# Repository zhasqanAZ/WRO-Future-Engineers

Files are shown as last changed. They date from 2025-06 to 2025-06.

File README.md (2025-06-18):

# <h1 align="center"> ZHANYM </h1> 

This repository showcases the journey and development of our robot created for the **2025 World Robot Olympiad – Future Engineers** category.

We are **Team Zhanym WRO2025**, a duo of passionate and driven girls who designed, engineered, and built this robot from the ground up.

Here, you'll find all the documentation, design insights, and technical details behind our project.

<p align="center">
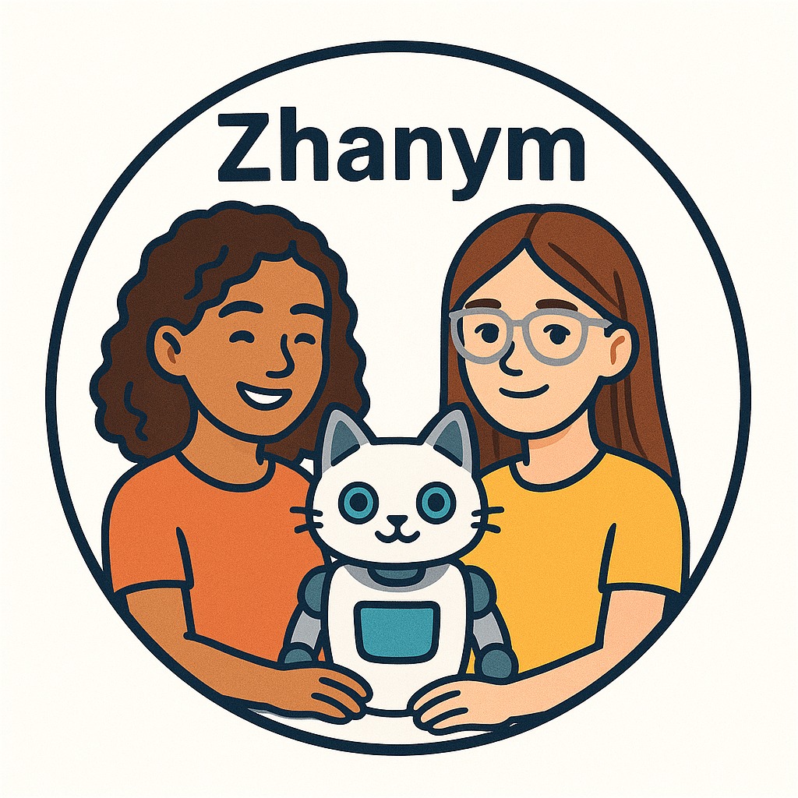
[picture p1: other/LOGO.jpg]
Team Logo
  
</p>

## Team Members 
### Khanbay Aigerim
Hello! 👋

My name is **Aigerim**, and I am **17 years old**.

This is my **second adventure** in the **WRO (World Robot Olympiad)** — a journey that fuels my passion for innovation and technology.

My first experience was back in **Grade 9**, when I took on the challenge of the **RoboMission category (Senior Division)**.  
That experience sparked my love for robotics and teamwork.

Now, I'm excited to take things to the next level as I dive into the **Future Engineers** category — where creativity, design, and real-world engineering come together! 🚀
.

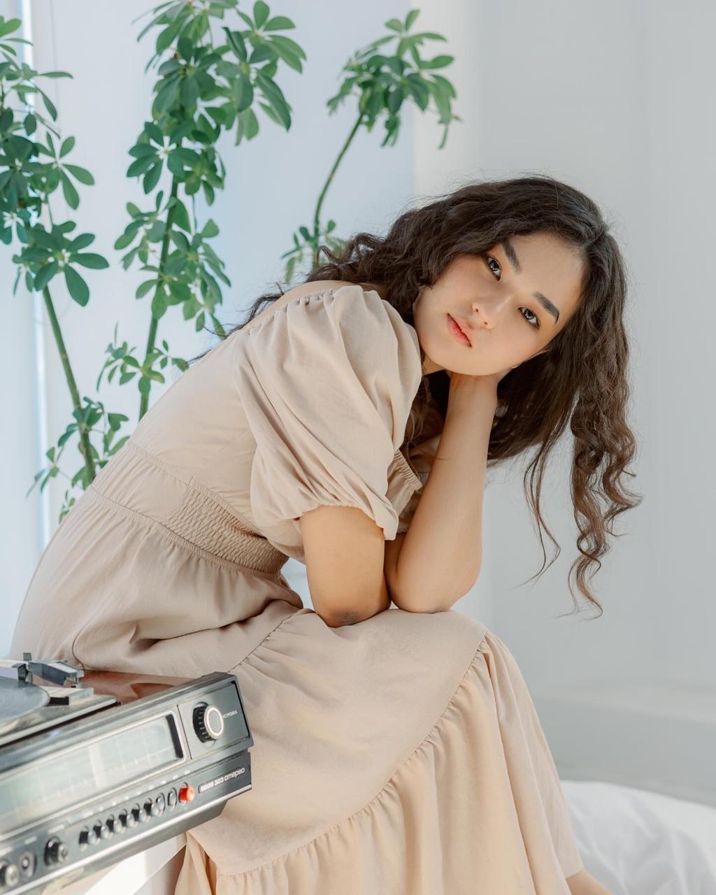
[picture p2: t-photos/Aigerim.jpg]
Aigerim


### Zharas Zhanuya
Hi! 👋

I’m **Zhanuya**, a **16-year-old student** passionate about **engineering**, **coding**, and **hands-on problem solving**.

I love working on tech projects that combine **hardware and creativity**.

Last year, I competed in the **WRO Future Engineers** category,  
and I’m excited to keep learning and building in this category! 🚀

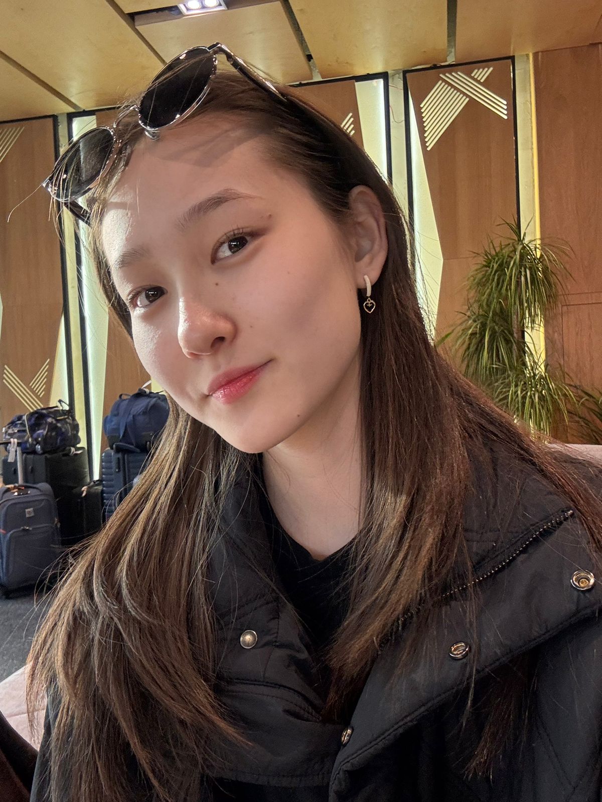
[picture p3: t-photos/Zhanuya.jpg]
Zhanuya


### 👨‍🏫 Mentor: Mister Askar
Hello! My name is **Askar**, and I am the **mentor** of this amazing team.

I’m truly happy to work with such talented and motivated students who are passionate about engineering, creativity, and robotics.

Guiding them through challenges and helping them grow is a privilege and a joy.

I also work at **Nazarbayev Intellectual School (NIS)** in **Atyrau**, where I support young minds in exploring STEM fields and developing real-world problem-solving skills.

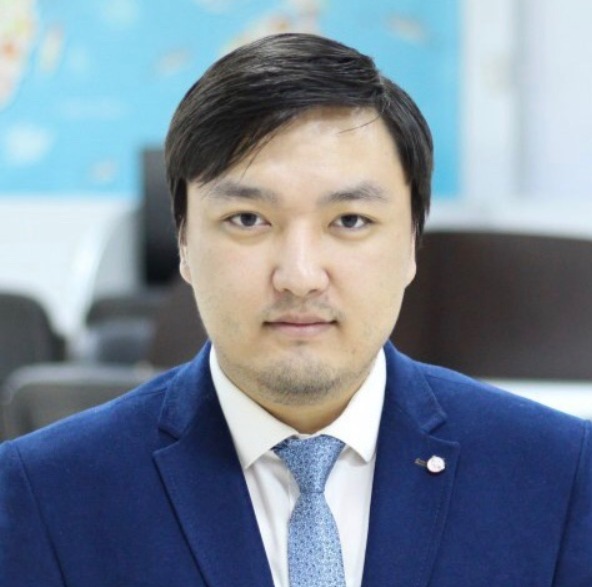
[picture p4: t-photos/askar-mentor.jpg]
Askar - Mentor


---

## Autonomous Robotic Vehicle

This autonomous robotic vehicle is capable of self-driving on a dynamically changing racetrack, completing multiple laps without human input and adapting to new configurations in each round.
<div style="width: 100%; display: flex; justify-content: center; margin-top: 40px;">
  <table style="background-color: #f0f0f0; text-align: center; border-collapse: collapse; font-family: Arial, sans-serif; transform: scale(1.2);">
    <tr>
      <td style="padding: 20px;">
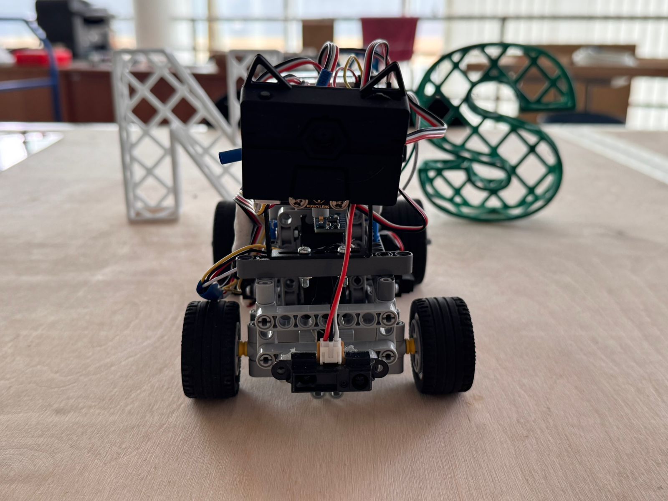
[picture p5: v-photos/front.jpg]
        <br><strong>Front</strong>
      </td>
      <td style="padding: 20px;">
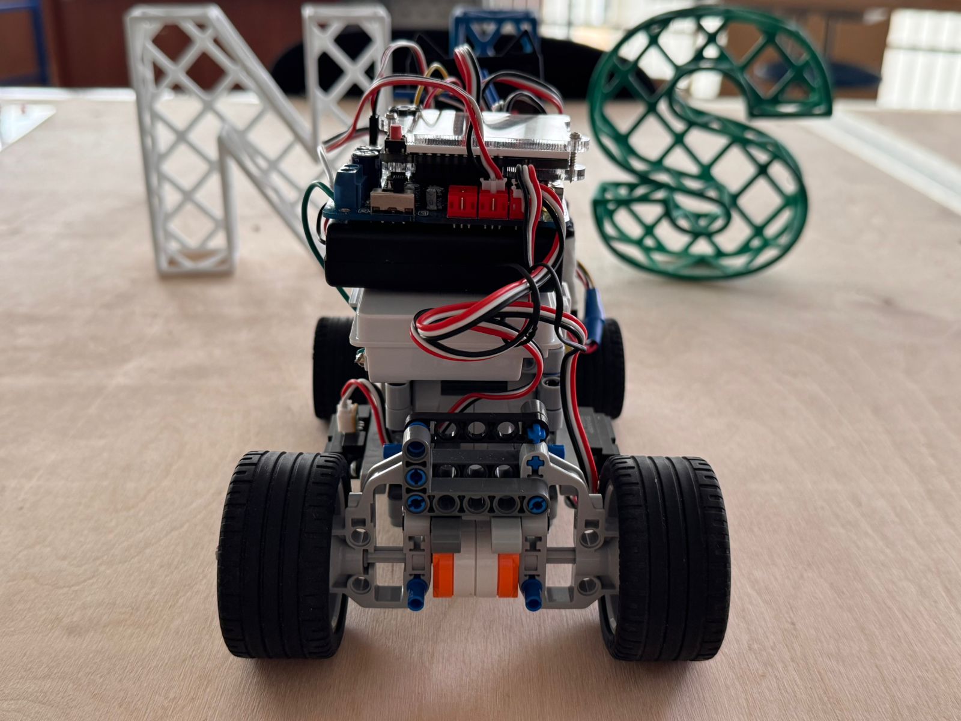
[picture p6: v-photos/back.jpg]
        <br><strong>Back</strong>
      </td>
    </tr>
    <tr>
      <td style="padding: 20px;">
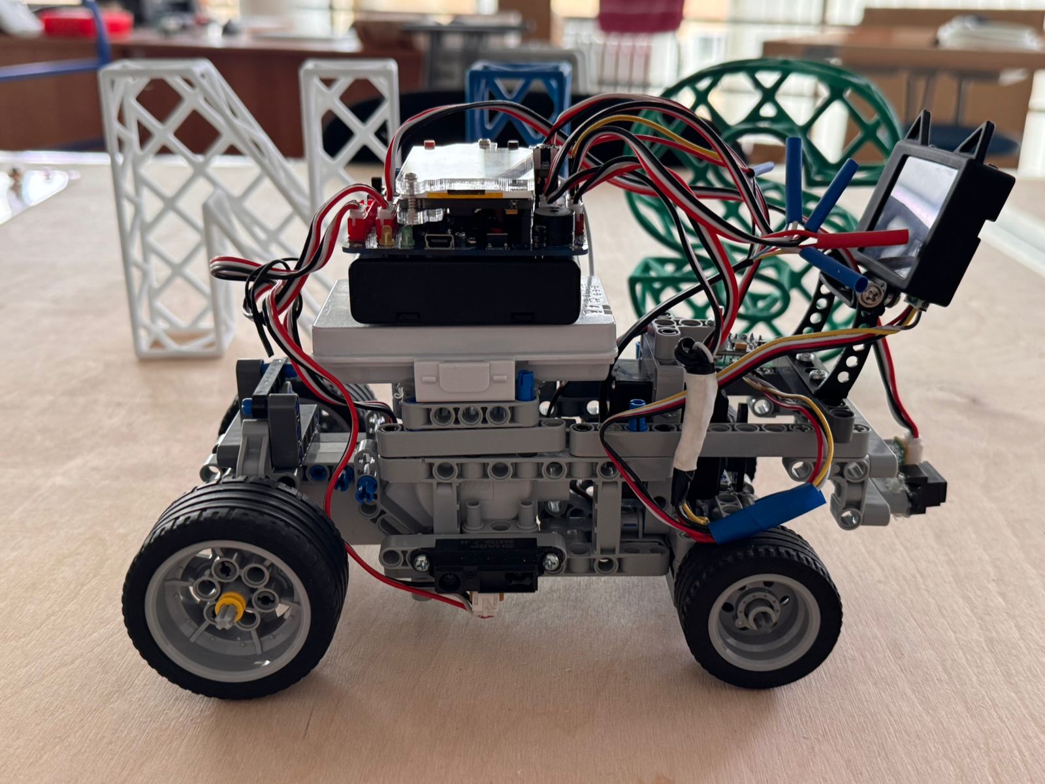
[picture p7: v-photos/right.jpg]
        <br><strong>Right</strong>
      </td>
      <td style="padding: 20px;">
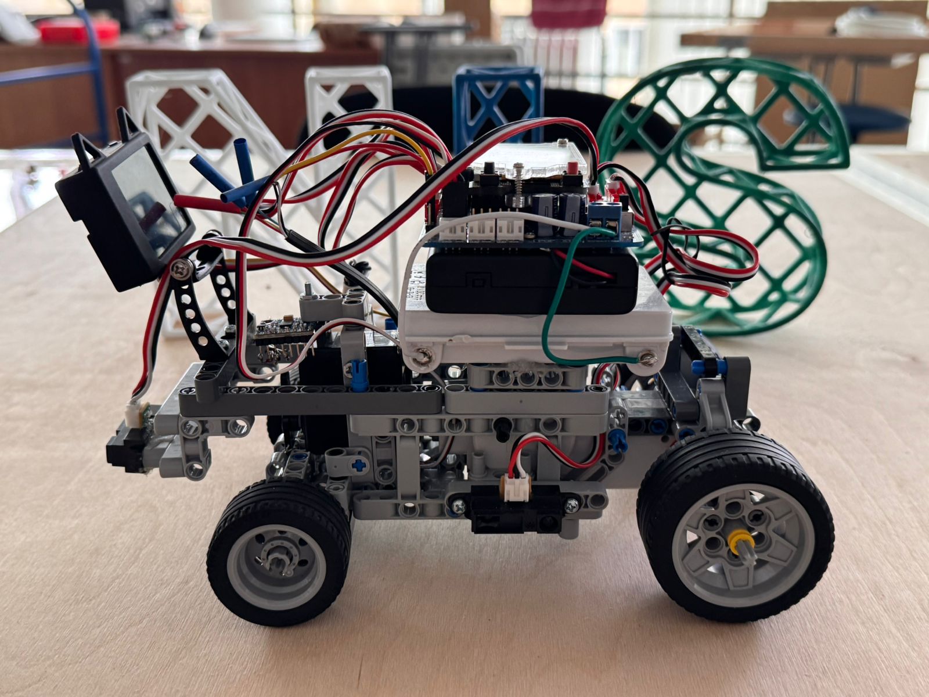
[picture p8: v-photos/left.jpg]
        <br><strong>Left</strong>
      </td>
    </tr>
    <tr>
      <td style="padding: 20px;">
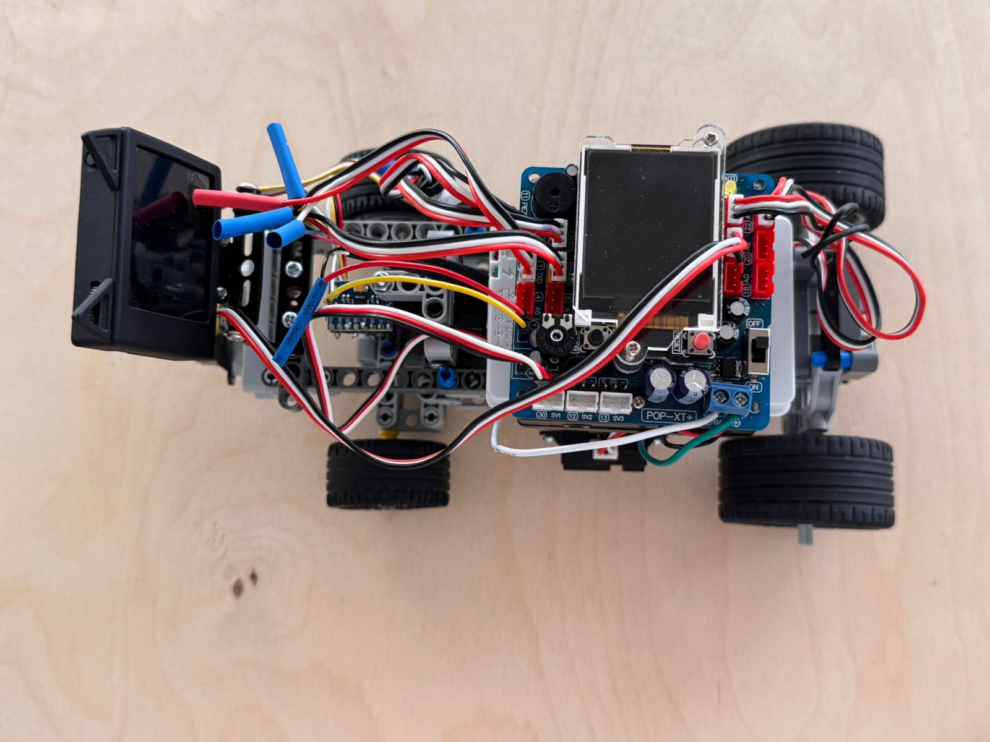
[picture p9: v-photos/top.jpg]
        <br><strong>Top</strong>
      </td>
      <td style="padding: 20px;">
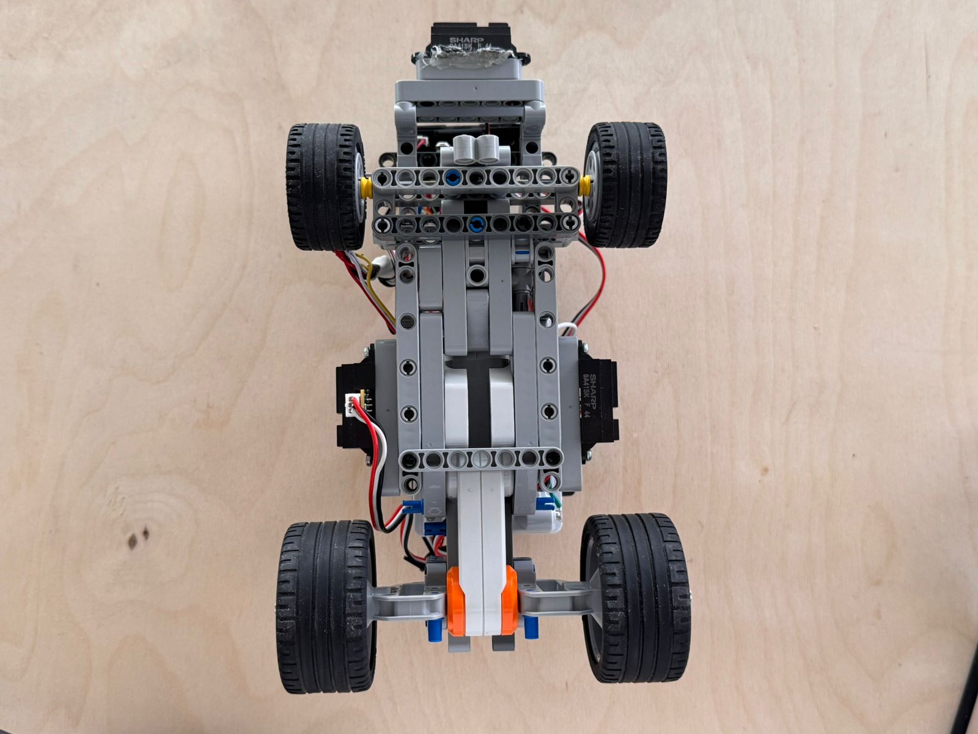
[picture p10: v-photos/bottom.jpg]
        <br><strong>Bottom</strong>
      </td>
    </tr>
  </table>
</div>
<p align="center">
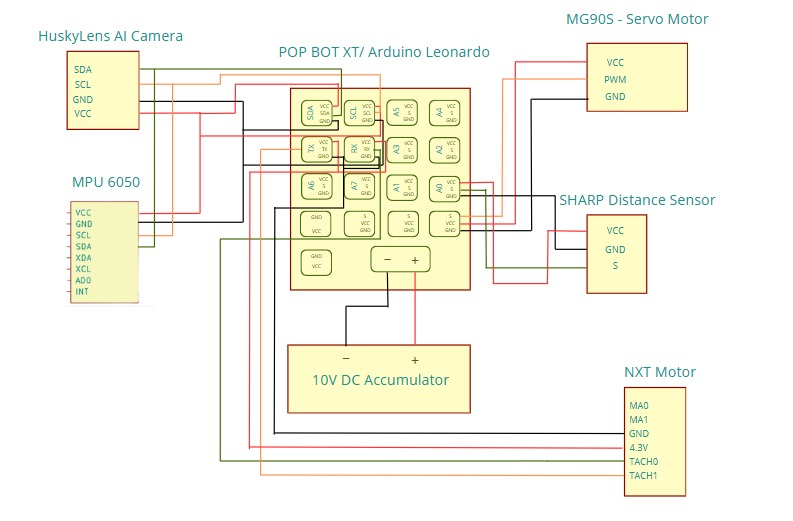
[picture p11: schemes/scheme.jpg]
scheme

</p>

The following schematic illustrates the connections of all electrical components. The MPU6050 and HuskyLens modules are connected via the I2C interface. The Sharp distance sensors are connected to the analog input pins. Both the DC motor and the servo motor are connected to port 1, while the encoder of the DC motor is connected through the TX and RX pins.

**[🎬 Watch Video](https://youtu.be/Wi_wQ2bi3kk?si=jCcD25NxIpxFfM3Z)**

## Engineering Documentation Overview

This documentation outlines the key components of the engineering process involved in the development and operation of the autonomous vehicle. It provides an overview of the following subsystems:

### Mobility Control
Design and implementation of systems responsible for the vehicle's movement, including speed regulation, turning mechanisms, and path-following algorithms.

### Power and Sensory Management
Integration and management of the vehicle’s power supply, along with configuration and usage of various sensors. These sensors deliver essential environmental data used by the robot’s decision-making systems.

### Obstacle Navigation and Avoidance
Development of strategies and systems that allow the vehicle to detect, assess, and navigate around obstacles. This includes both hardware and software components required for safe and effective performance in the Obstacle Challenge.

# Mobility Control
## ⚙️ Mobility Control

### Evolution of Design

Over the course of development, we built and tested **three different chassis and drive configurations** to find the most reliable and competition-ready setup.

#### 🔧 First Version: EV3-Based Rear-Wheel Drive  
- **Motors**: Large EV3 motor for rear-wheel drive, Medium EV3 motor for steering  
- **Platform**: Open-source Linux-based EV3 firmware  
- **Pros**: Familiar platform, easy sensor integration  
- **Cons**: Long upload times, significant turning inaccuracies due to software delays and large motor inertia
<p align="center">
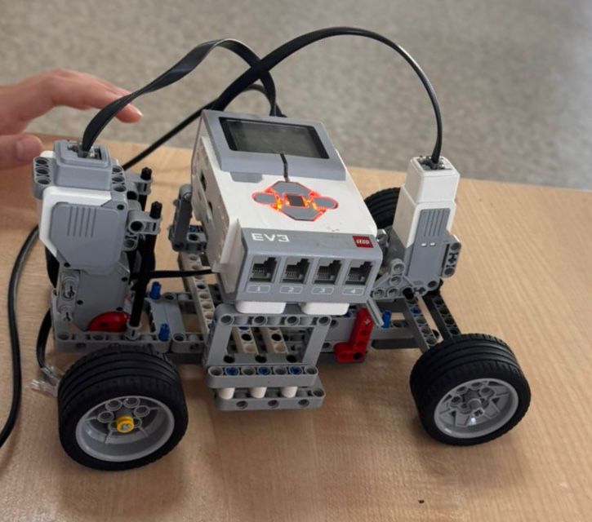
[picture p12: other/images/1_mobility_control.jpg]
Mobility Control
  
</p>

#### 🔧 Second Version: Front-Wheel Drive with DC Gearbox Motors  
- **Motors**: Two front-mounted DC gearbox motors + front servo for steering  
- **Platform**: POP-BOT XT board with direct wiring  
- **Pros**: Improved maneuverability  
- **Cons**: Required a lot of internal space for motor connections; turning errors due to all movement being concentrated in the front wheels
  <p align="center">
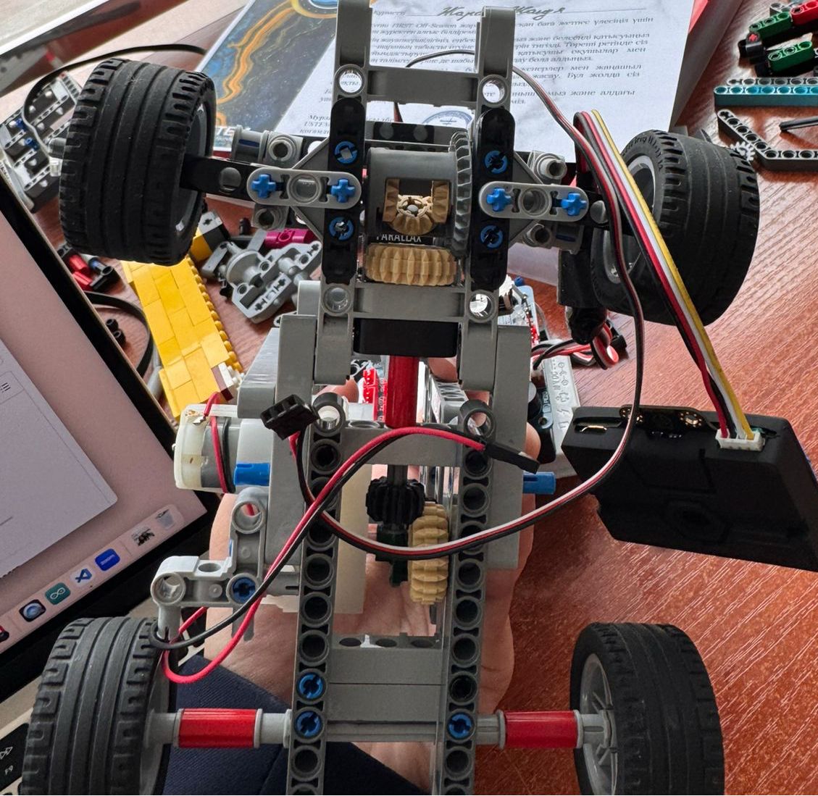
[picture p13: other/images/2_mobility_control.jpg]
Mobility Control
  
</p>

🔧 **Third Version: Rear-Wheel Drive with EV3 Medium Motor for Steering**  
**Motors**: NXT motor for rear-wheel drive, Medium EV3 motor for steering  
**Drive Configuration**: Rear-wheel drive  
**Platform**: POP-BOT XT board  

**Pros**: Compact rear-wheel drive setup, stable at higher speeds  
**Cons**: Steering lacked precision since it was controlled by power level instead of angle, which led to inaccurate turns and difficulty in fine adjustments  
 <p align="center">
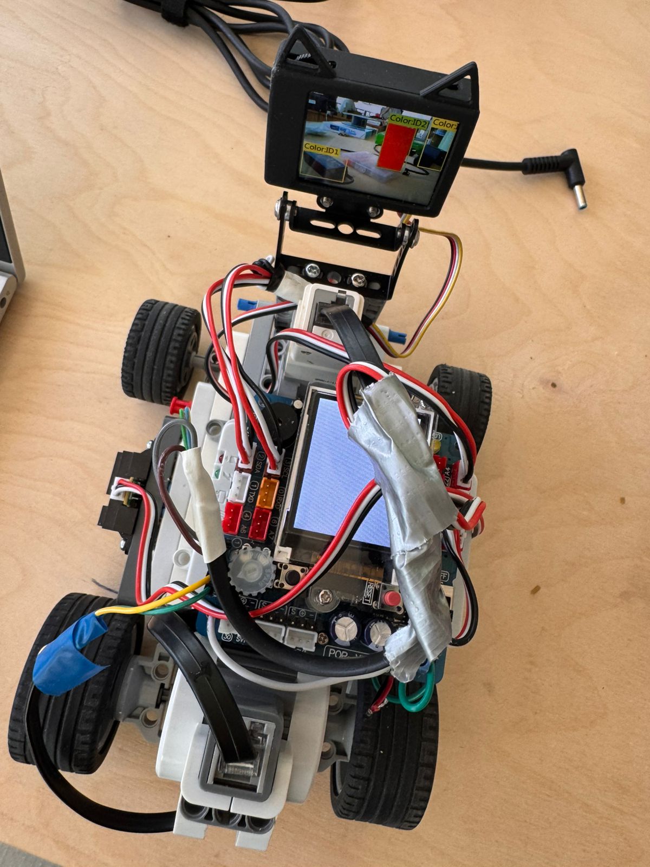
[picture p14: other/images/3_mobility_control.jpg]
Mobility Control
  
</p>

#### ✅ Final Version: Rear-Wheel Drive with NXT Motor and Parallax Servo  
- **Motors**: NXT motor for drive, Parallax continuous rotation servo for steering  
- **Drive Configuration**: Rear-wheel drive  
- **Improvements**:  
- **Rear-wheel drive** offers better traction and improved directional stability, especially at higher speeds  
- The **Parallax servo** enables precise angular steering, making turns smoother and more accurate
   
<p align="center">
  Mobility Control
</p>

---

### 🔩 Drivetrain & Motors

- **Drive Motor**: LEGO NXT motor  
- **Mounting**: Connected to the rear axle using a custom holder  
- **Motor Driver**: Integrated with POP-BOT XT board  
- **Steering Mechanism**: Parallax continuous rotation servo motor connected to the front wheels  
 
### Potential Improvements
- Upgrade NXT motor to a lighter high-efficiency DC motor to reduce weight and increase speed control  
- Implement position feedback from the servo for dynamic steering correction  
- Add soft damping or suspension to reduce shaking on uneven surfaces  

### Motor Components in Final Version

<p align="center">
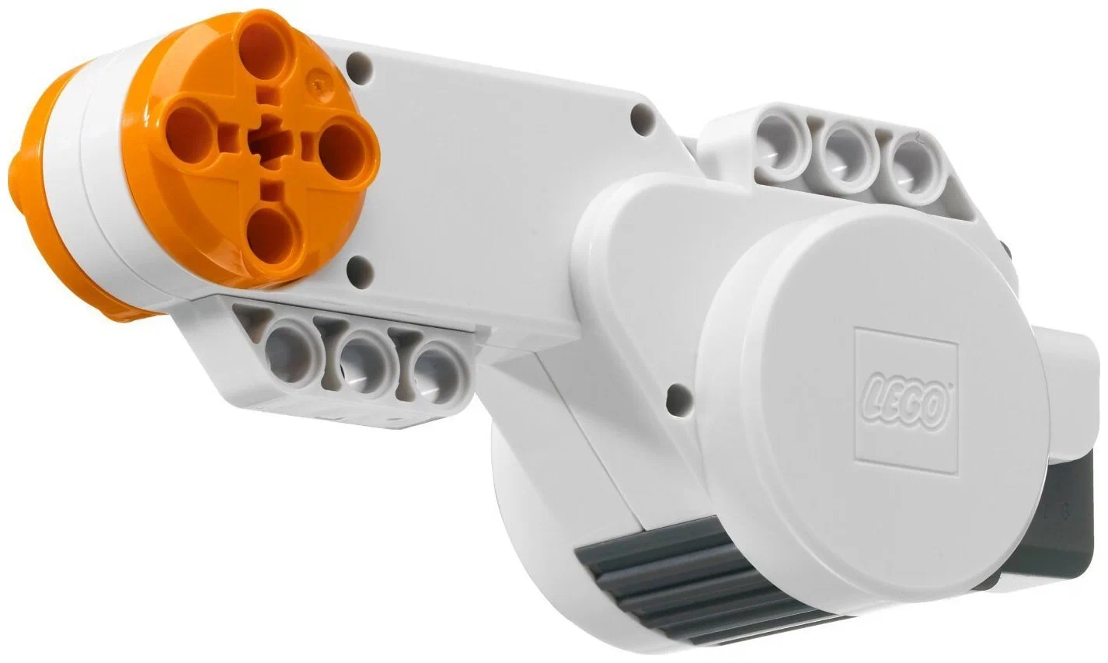
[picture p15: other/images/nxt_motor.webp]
LEGO NXT Motor
  
</p>

#### ⚙️ LEGO NXT Motor  
- **Description**: 9 V DC motor with 48:1 internal gearbox and optical encoder (~1° resolution) 
- **Key Specs**:  
  - Built-in optical encoder provides position feedback 
  - Gear reduction gives high torque at low RPM 
- **Advantages**: precise movement control, reliable performance in robotic applications  
- **Disadvantages**: heavier than micro DC options; limited top speed  
- **Usage**: used for rear-wheel drive

---

<p align="center">
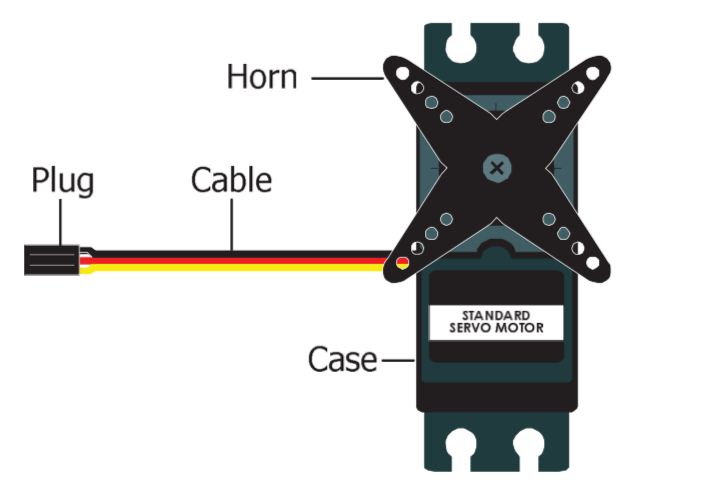
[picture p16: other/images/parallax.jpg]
Parallax Continuous Rotation Servo
  
</p>

#### 🌀 Parallax Continuous Rotation Servo (900‑00008)  
- **Description**: continuous-rotation servo made by Parallax (Futaba gear set), designed for PWM control of speed and direction
- **Key Specs** (900‑00008):  
  - Operating voltage: 4–6 V DC 
  - Torque: ~2.7 kg·cm (4.8 V) up to ~3.0 kg·cm (6 V) 
  - Speed: ~50–60 RPM (no load) 
  - Weight: ~42–45 g 
- **Advantages**: precise angular steering via PWM (1300–1700 µs pulse widths) 
- **Considerations**: requires calibration (center potentiometer adjustment) 
- **Usage**: used for steering mechanism in final version

---

### 🏗️ Control Board: POP‑BOT XT

<p align="center">
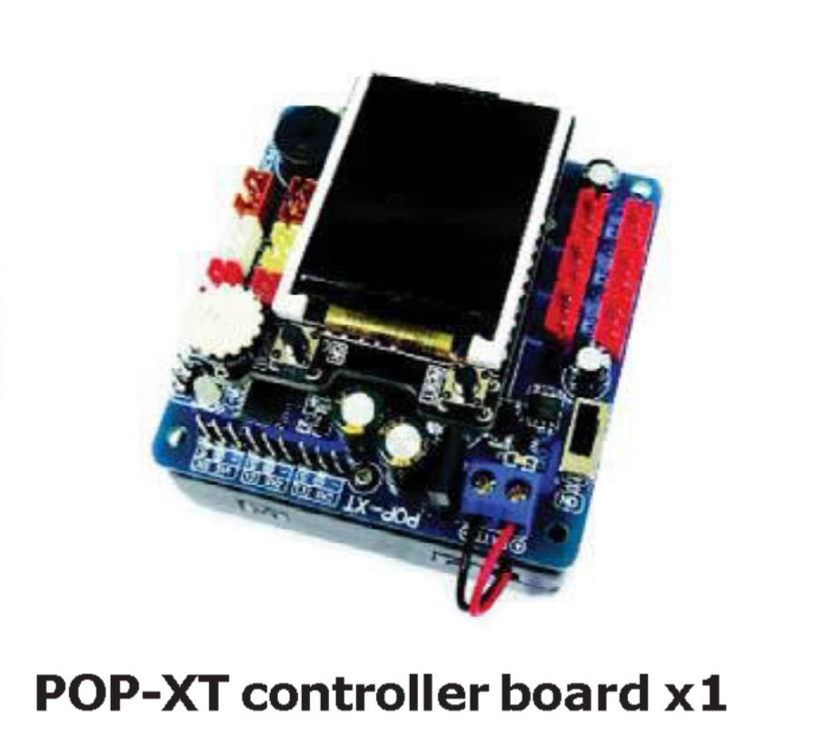
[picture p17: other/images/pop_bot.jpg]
POP‑BOT XT Board
  
</p>

#### 🧭 POP‑BOT XT (Arduino Leonardo–compatible)

- **Microcontroller**: ATmega32U4, 16 MHz, preloaded with Arduino Leonardo bootloader  
- **Memory**: 32 KB Flash, 2.5 KB SRAM, 1 KB EEPROM  
- **I/O**: 12 analog inputs, digital I/O pins, I²C, UART, and SPI communication  
- **Motor Drivers**: Two built-in DC motor drivers, three JST headers for servos (4.8–7.2 V supported)  
- **Power Supply**: Powered by 4 × AA batteries (4.8–6 V), with onboard step-up/step-down voltage regulator (+5 V)  
- **Other Features**: Integrated 1.8" color graphic LCD (128×160, 262K colors), USB programmable without external hardware  
- **Advantages**: All-in-one robotics platform — microcontroller, motor drivers, power management, and display in a single board  
- **Usage in Our Robot**: Acts as the central control unit; both the NXT motor (drive) and the Parallax continuous rotation servo (steering) are connected to this board  

## 🔌 Power and Sensory Management

Integration and management of the vehicle’s power supply, along with configuration and usage of various sensors. These sensors deliver essential environmental data used by the robot’s decision-making systems.

---

### 📷 HuskyLens AI Camera

<p align="center">
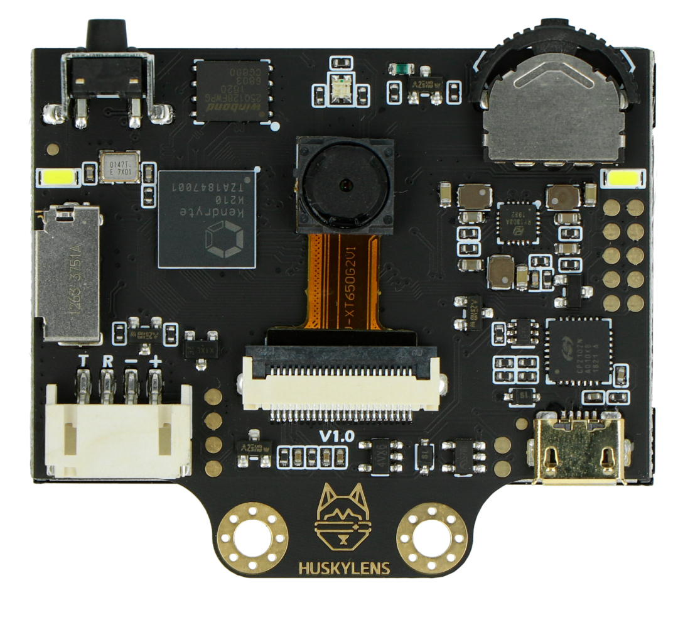
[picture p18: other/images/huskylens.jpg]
HuskyLens AI Camera
  
</p>

- **Description**: Smart vision sensor with built-in machine learning algorithms  
- **Key Features**:
  - Recognizes lines, objects, colors, faces, QR codes, and tags
  - Built-in UART/I2C communication interface  
- **Operating Voltage**: 3.3 V – 5 V  
- **Usage**:
# 🤖 POP-BOT XT Self-Driving Robot — WRO2025

---
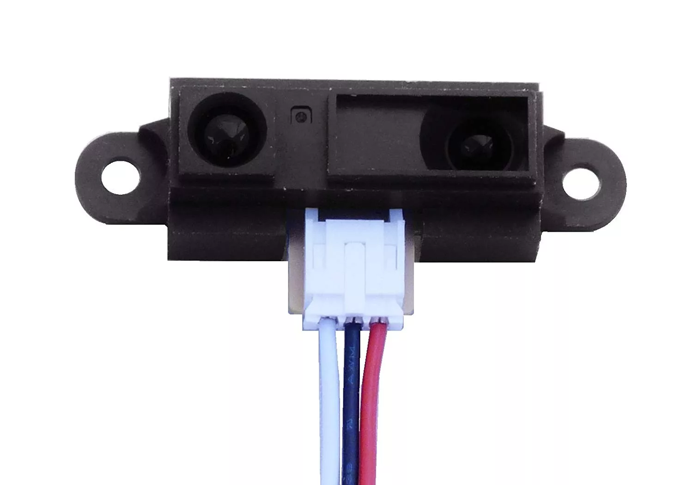
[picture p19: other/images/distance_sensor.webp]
Sharp IR Sensor

Description: Infrared analog distance sensor for short-range object detection

Key Features:

Detects objects in the range of 10 cm – 80 cm

Non-contact distance measurement using infrared reflection

Analog output voltage inversely proportional to distance

Model: Sharp GP2Y0A21YK0F (or compatible)

Operating Voltage: 4.5 V – 5.5 V

Interface: Analog (connects to analog input pin)

Typical Output: ~3.0 V at 10 cm, ~0.4 V at 80 cm

Usage:
Used for obstacle detection, wall-following, and precise distance measurement in robotics applications like the POP-BOT XT Self-Driving Robot — WRO2025

```cpp

#include <popxt.h>

int distRight, distLeft, distFront;

void setup() {
  setTextSize(2);
  glcdMode(2);
  glcdClear();
  glcd(2, 1, "Press OK");
  sw_ok_press();  // Ожидаем нажатие кнопки OK
  glcdClear();
  glcd(1, 1, "Start Driving...");
  delay(1000);
}

void loop() {
  // ======= Движение вперёд =======
  glcd(0, 1, "Moving Forward");
  motor(2, 100); // Оба мотора вперёд

  while (true) {
    distFront = getdist(4); // A4 — фронтальный датчик

    char buf[21];
    sprintf(buf, "Front: %d cm   ", distFront);
    glcd(2, 1, buf);

    if (distFront <= 15) {
      // ======= Слишком близко: отъехать назад =======
      glcd(0, 1, "Too Close! Back");
      motor(2, -50);   // Назад
      delay(1200);
      motor(2, 0);
      delay(200);
      break;  // Прерываем цикл — продолжим анализ
    } else if (distFront <= 25) {
      // ======= Препятствие на рабочем расстоянии: остановиться и повернуть =======
      motor(2, 0);  // Стоп
      delay(100);
      
      // ======= Чтение боковых датчиков =======
      distLeft = getdist(2);   // A2 — левый
      distRight = getdist(5);  // A0 — правый

      char buf[21];
      sprintf(buf, "L:%d R:%d       ", distLeft, distRight);
      glcd(3, 1, buf);
      delay(50);

      if (distLeft > distRight) {
        glcd(0, 1, "Turn left    ");
        motor(1, -35);  // Левый мотор назад — поворот налево
        delay(500);
        motor(2, 100);   // Правый мотор вперёд
        delay(1600);
        motor(2, 0);
        motor(1,35);   // Левый мотор вперёд — коррекция
        delay(500);
      } else {
        glcd(0, 1, "Turn right   ");
        motor(1, 30);   // Левый мотор вперёд — поворот направо
        delay(300);
        motor(2, 100);   // Правый мотор вперёд
        delay(1600);
        motor(2, 0);
        motor(1, -30);  // Левый мотор назад — коррекция
        delay(300);
      }

      delay(100);
      break;  // После поворота выходим из цикла, чтобы ехать снова
    }

    // Если расстояние больше 25 см — продолжаем ехать вперёд
    delay(50);
  }

  // ======= Очистка экрана перед следующим циклом =======
  glcdClear();
  glcd(1, 2, "Looping...");

  delay(500);  // Немного подождать перед новой итерацией
}

``` 

This repository contains Arduino-based code for a self-driving robot using the **POP-BOT XT** platform, **HuskyLens AI camera**, **Sharp Distance Sensor** and **MPU6050 gyroscope**.  
It includes multiple stages of robot behavior: color-based navigation, obstacle avoidance, and gyroscopic stabilization.

---

## 🚦 Stage 1: Color-Based Navigation

The robot moves forward and recognizes **blue** and **orange** color tags using the HuskyLens camera.  
Depending on the color detected, it turns **left** (blue) or **right** (orange).

### Code:
```cpp
#include <popxt.h>
#include <Wire.h>
#include "HUSKYLENS.h"

#define DRIVE_MOTOR 1

HUSKYLENS huskylens;
bool actionTaken = false;

void stopMotor() {
  motor(DRIVE_MOTOR, 0);
}

void moveForward30cm() {
  motor(DRIVE_MOTOR, 70);
  delay(1300);
  stopMotor();
}

void turn90deg() {
  motor(DRIVE_MOTOR, 80);
  delay(1700);
  stopMotor();
}

void resumeMovement() {
  servo(1, 88);
  motor(DRIVE_MOTOR, 70);
  actionTaken = false;
  glcdClear();
  glcd(1, 1, "Looking for color...");
}

void setup() {
  setTextSize(1);
  glcdMode(2);
  glcdClear();
  glcd(1, 1, "Press OK");

  Wire.begin();
  huskylens.begin(Wire);

  sw_ok_press();
  glcdClear();
  glcd(1, 1, "Looking for color...");
}

void loop() {
  if (actionTaken) return;

  servo(1, 88);
  motor(DRIVE_MOTOR, 70);

  while (!actionTaken) {
    if (huskylens.request()) {
      while (huskylens.available()) {
        HUSKYLENSResult result = huskylens.read();

        if (result.ID == 3) {
          glcdClear();
          glcd(1, 1, "Orange detected");
          moveForward30cm();
          servo(1, 40);
          delay(300);
          turn90deg();
          servo(1, 88);
          delay(300);
          resumeMovement();
          break;

        } else if (result.ID == 4) {
          glcdClear();
          glcd(1, 1, "Blue detected");
          moveForward30cm();
          servo(1, 114);
          delay(300);
          turn90deg();
          servo(1, 88);
          delay(300);
          resumeMovement();
          break;
        }
      }
    }

    delay(100);
  }
}
``` 

---

## Stage 2 (Obstacle Challenge): Recognizes the color of blocks (e.g., red/green) to make navigation decisions accordingly
This code enables the robot to detect large green or red objects using the HuskyLens AI camera and perform obstacle avoidance maneuvers by turning left or right, respectively, while continuing forward when the path is clear.

```cpp
#include <Wire.h>
#include <popxt.h>         // For controlling motors, servo, and screen
#include "HUSKYLENS.h"     // HuskyLens AI Camera library

HUSKYLENS huskylens;

// Color IDs from HuskyLens training
#define GREEN_ID 1
#define RED_ID 2

// Minimum size threshold to consider the object as an obstacle
#define WIDTH_THRESHOLD 90
#define HEIGHT_THRESHOLD 150

#define DRIVE_MOTOR 1      // Single drive motor on rear wheels

void setup() {
    Serial.begin(115200);
    Wire.begin();

    glcdClear();
    glcd(0, 0, "Initializing...");

    // Initialize HuskyLens until success
    while (!huskylens.begin(Wire)) {
        Serial.println(F("Begin failed! Check I2C connection and protocol settings."));
        glcd(0, 1, "HUSKY error...");
        delay(500);
    }

    // Set algorithm to color recognition
    huskylens.writeAlgorithm(ALGORITHM_COLOR_RECOGNITION);
    glcd(0, 1, "Color mode ready!");
    stopMotors();
    delay(1000);
    glcdClear();
    setTextSize(1);
    glcdMode(2);

    // Wait for user to press OK button
    glcd(0, 0, "Press OK to start");
    sw_ok_press();
    glcdClear();
    glcd(0, 0, "Started!");
    delay(500);
}

void loop() {
    glcdClear();
    Serial.println("Loop running...");

    if (huskylens.request()) {
        bool obstacleDetected = false;

        // Iterate through detected color blocks
        for (int i = 0; i < huskylens.countBlocks(); i++) {
            HUSKYLENSResult result = huskylens.getBlock(i);

            // Consider only large enough objects
            if (result.width >= WIDTH_THRESHOLD || result.height >= HEIGHT_THRESHOLD) {
                obstacleDetected = true;

                if (result.ID == GREEN_ID) {
                    glcd(0, 0, "Green object!");
                    glcd(0, 1, "Avoid LEFT");
                    Serial.println("Big green object — avoid to the LEFT.");
                    avoidLeft();
                } else if (result.ID == RED_ID) {
                    glcd(0, 0, "Red object!");
                    glcd(0, 1, "Avoid RIGHT");
                    Serial.println("Big red object — avoid to the RIGHT.");
                    avoidRight();
                }
                break;  // Exit loop after first large object
            }
        }

        if (!obstacleDetected) {
            glcd(0, 0, "Clear path");
            glcd(0, 1, "Moving forward");
            Serial.println("No big object — moving forward.");
            goForward();
        }

    } else {
        glcd(0, 0, "Looking for");
        glcd(0, 1, "color object...");
        Serial.println("No object detected, moving forward.");
        goForward();
    }

    delay(100);
}

// Movement control functions

void goForward() {
    Serial.println("Going forward");
    servo(1, 88);               // Steering straight
    motor(DRIVE_MOTOR, 70);     // Drive forward
}

void stopMotors() {
    motor(DRIVE_MOTOR, 0);
}

// Turn the robot 90° left
void turnLeft90() {
    servo(1, 114);              // Turn wheels left
    delay(300);
    motor(DRIVE_MOTOR, 80);
    delay(500);
    stopMotors();
    servo(1, 88);               // Straighten wheels
    delay(300);
}

// Turn the robot 90° right
void turnRight90() {
    servo(1, 40);               // Turn wheels right
    delay(300);
    motor(DRIVE_MOTOR, 80);
    delay(500);
    stopMotors();
    servo(1, 88);               // Straighten wheels
    delay(300);
}

// Avoid obstacle by going left and returning to path
void avoidLeft() {
    stopMotors();
    delay(100);
    turnLeft90();
    motor(DRIVE_MOTOR, 70);
    delay(300);
    turnRight90();
    motor(DRIVE_MOTOR, 70);
    delay(800);
    stopMotors();
}

// Avoid obstacle by going right and returning to path
void avoidRight() {
    stopMotors();
    delay(100);
    turnRight90();
    motor(DRIVE_MOTOR, 70);
    delay(300);
    turnLeft90();
    motor(DRIVE_MOTOR, 70);
    delay(800);
    stopMotors();
}

``` 

### 📐 MPU6050 Gyroscope + Accelerometer
This code uses data from the MPU6050 gyroscope to maintain straight-line motion by dynamically adjusting the steering angle based on yaw correction.

PID Regulator with MPU6050                                                                                                                                           The MPU6050 provides real-time angle or motion data. The PID controller compares the current value (from MPU) with a target (setpoint) and adjusts the output (e.g., motor speed or servo position) to correct the difference.

P (Proportional): Reacts to current error

I (Integral): Reacts to accumulated past error

D (Derivative): Reacts to predicted future error (rate of change)

Together, they ensure smooth and stable correction, avoiding overshooting or oscillation.

<p align="center">
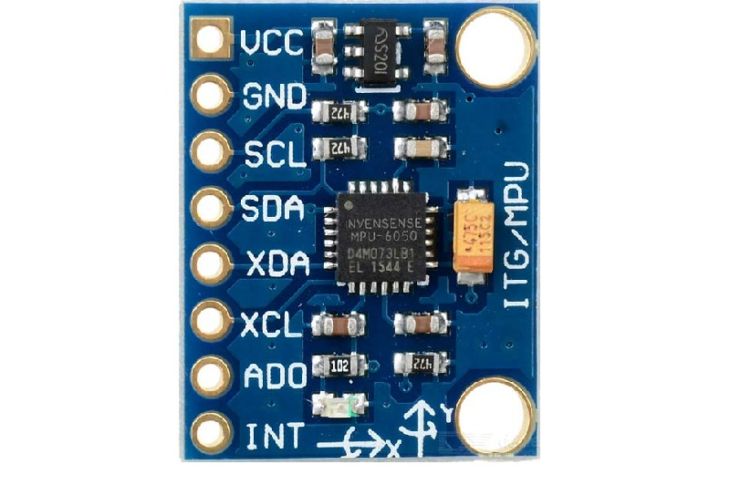
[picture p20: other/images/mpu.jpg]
MPU6050 Sensor
  
</p>

- **Description**: 6-axis motion tracking device (3-axis gyroscope + 3-axis accelerometer)  
- **Key Features**:
  - I2C communication  
  - Integrated Digital Motion Processor (DMP)  
- **Operating Voltage**: 3 V – 5 V  
- **Usage**:
  - The robot uses the **gyroscope** to measure angular rotation, enabling more precise turns and directional stability  
  - Helps to smooth out turning behavior, especially during sharp cornering

```cpp
#include <Wire.h>
#include <MPU6050_light.h>
#include <popxt.h>

MPU6050 mpu(Wire);

#define DRIVE_MOTOR 1
#define SERVO_PIN 1
#define BASE_SERVO 88
#define DEAD_ZONE 0.01

float Kp = 4.5;
float Kd = 1.8;

float yaw = 0.0;
float targetYaw = 0.0;
float prevError = 0.0;
unsigned long lastTime = 0;

int currentSteer = BASE_SERVO;
bool started = false;

void setup() {
  Wire.begin();
  mpu.begin();
  mpu.calcGyroOffsets();

  sw_ok_press();         // Ждём кнопку
  mpu.calcGyroOffsets(); // Повторная калибровка

  servo(SERVO_PIN, BASE_SERVO);
  lastTime = millis();
}

void loop() {
  if (!started) {
    motor(DRIVE_MOTOR, 70);
    started = true;
  }

  mpu.update();

  float dt = (millis() - lastTime) / 1000.0;
  lastTime = millis();

  float gz = mpu.getGyroZ();
  if (abs(gz) < DEAD_ZONE) gz = 0;
  yaw += gz * dt;

  float error = targetYaw - yaw;
  float derivative = (error - prevError) / dt;
  prevError = error;

  float output = constrain(Kp * error + Kd * derivative, -25, 25);
  int targetSteer = constrain(BASE_SERVO + output, 40, 130);

  if (targetSteer > currentSteer + 3)      currentSteer += 3;
  else if (targetSteer < currentSteer - 3) currentSteer -= 3;
  else                                     currentSteer = targetSteer;

  servo(SERVO_PIN, currentSteer);
  delay(50);
}
``` 

## Obstacle Navigation and Avoidance
This includes both hardware (HuskyLens AI Camera, motors, servos) and software (color recognition algorithms, motion logic) components to ensure safe and effective obstacle avoidance during the Obstacle Challenge.
The HuskyLens camera is trained to recognize specific colors in order to execute corresponding maneuvers and issue appropriate commands during navigation.

### The robot uses the HuskyLens AI camera in color recognition mode to identify specific trained colors.
<p align="center">
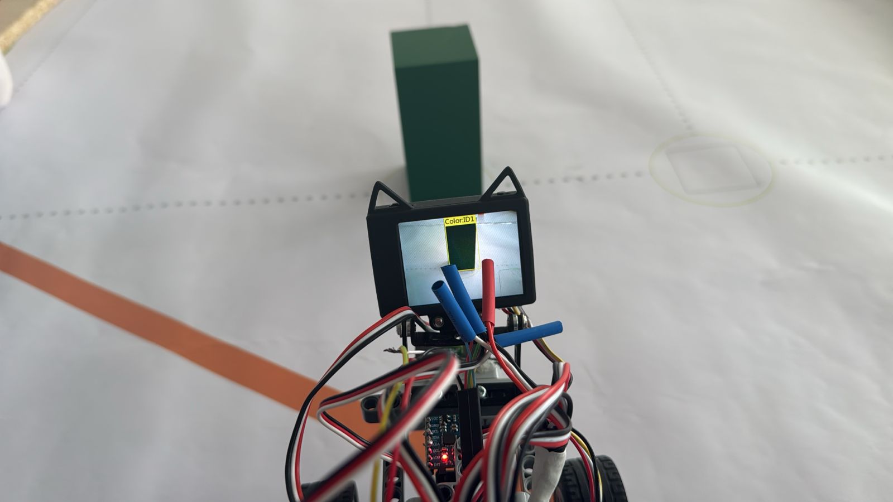
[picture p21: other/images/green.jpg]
green
  
</p>
When the HuskyLens camera detects a green-colored object (such as a brick), it triggers the robot to perform an avoidance maneuver by navigating around the obstacle from the left side.

<p align="center">
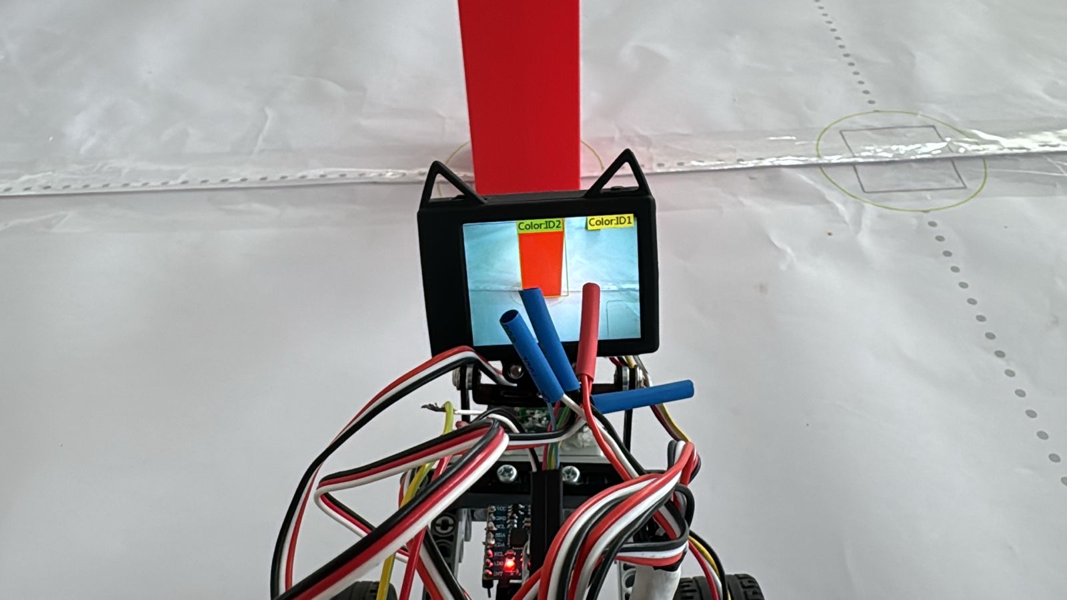
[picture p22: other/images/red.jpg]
red
  
</p>
When the HuskyLens camera detects a red-colored object (such as a brick), it triggers the robot to perform an avoidance maneuver by navigating around the obstacle from the right side.

<p align="center">
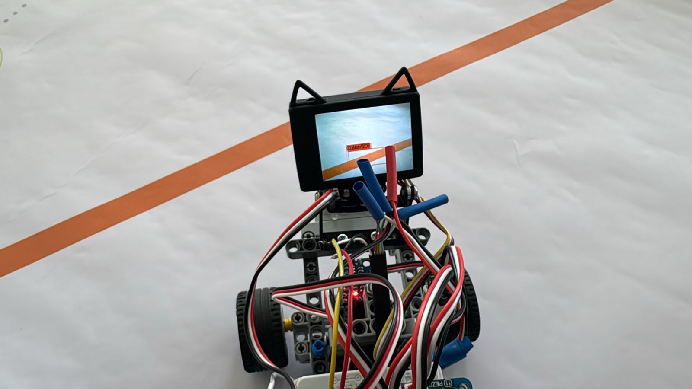
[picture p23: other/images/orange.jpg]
orange
  
</p>

The robot determines the direction of movement (clockwise or counterclockwise) based on the color of the line it detects. If the first line encountered is orange, this indicates that the robot should move in a clockwise direction, consistently turning right.
```cpp
 if (result.ID == 3) {
          glcdClear();
          glcd(1, 1, "Orange detected");
          moveForward30cm();
          servo(1, 40);
          delay(300);
          turn90deg();
          servo(1, 88);
          delay(300);
          resumeMovement();
          break;

``` 
---

<p align="center">
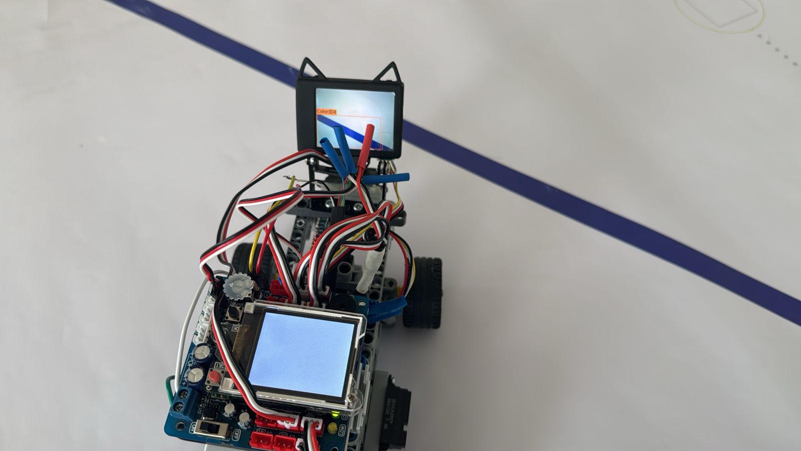
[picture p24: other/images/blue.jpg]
blue
  
</p>

The same logic applies to the blue color. If the robot detects a blue line first, it indicates that the movement should be counterclockwise. In this case, the robot moves forward when it sees the blue line and consistently turns left.

```cpp
        } else if (result.ID == 4) {
          glcdClear();
          glcd(1, 1, "Blue detected");
          moveForward30cm();
          servo(1, 114);
          delay(300);
          turn90deg();
          servo(1, 88);
          delay(300);
          resumeMovement();
          break;

``` 

---

<p align="center">
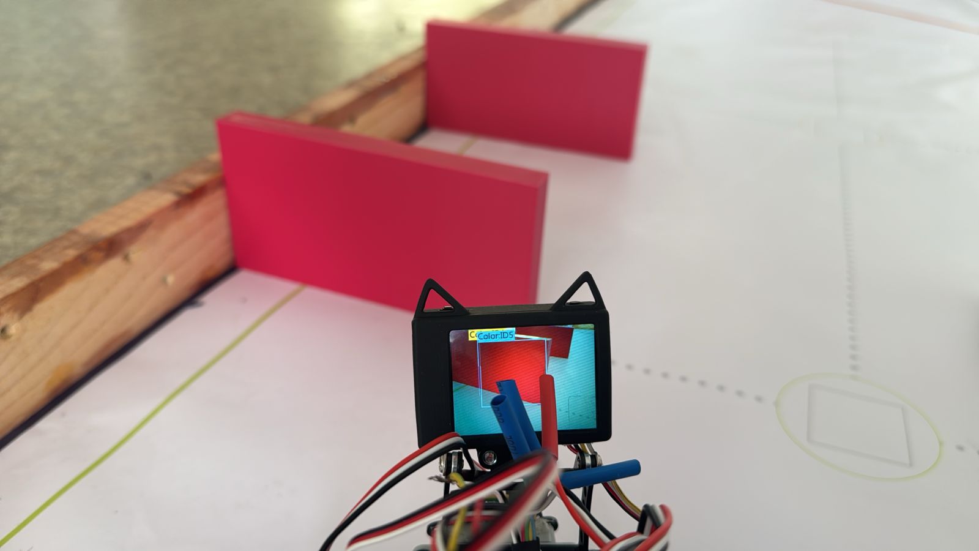
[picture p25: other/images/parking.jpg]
parking
  
</p>

After completing three full laps, the robot detects a parking zone marked with the color magenta. Upon recognition, it enters the zone and aligns itself parallel to the inner walls.

```cpp

#include <popxt.h>
#include <HUSKYLENS.h>
#include <Wire.h>

#define DRIVE_MOTOR 1
#define SERVO_PIN 1

HUSKYLENS huskylens;
String direction = "clockwise"; // или "counterclockwise", в зависимости от того, как определено ранее
bool parkingStarted = false;
bool aligned = false;
bool parked = false;
bool exited = false;

void setup() {
  Wire.begin();
  huskylens.begin(Wire);
  huskylens.writeAlgorithm(ALGORITHM_OBJECT_TRACKING);

  glcdMode(2);
  glcdClear();
  setTextSize(2);
  glcd(1, 1, "Waiting for ID5...");
}

void loop() {
  huskylens.request();

  // Ищем ID5 (парковку)
  for (int i = 0; i < huskylens.count(); i++) {
    HUSKYLENSResult block = huskylens.get(i);
    if (block.ID == 5 && !parkingStarted) {
      parkingStarted = true;
      glcdClear();
      glcd(1, 1, "Parking...");
      break;
    }
  }

  // Когда парковка началась
  if (parkingStarted && !aligned) {
    moveForward(800); // Едет прямо перед поворотом
    if (direction == "clockwise") {
      turnLeft(600); // Повернуть перпендикулярно парковке
    } else {
      turnRight(600);
    }
    aligned = true;
  }

  // Заезжает внутрь и выравнивается
  if (aligned && !parked) {
    moveForward(1000); // Заезд внутрь парковки
    delay(500);
    stopMotors();
    delay(500);
    servo(SERVO_PIN, 90); // Предположим, сервомотор выравнивает датчики или колёса
    parked = true;
    glcdClear();
    glcd(1, 1, "Parked.");
    delay(1000);
  }

  // Возвращается в начальное положение
  if (parked && !exited) {
    // Назад немного
    moveBackward(1000);
    if (direction == "clockwise") {
      turnRight(600); // Повернуться обратно
    } else {
      turnLeft(600);
    }
    moveForward(800); // Вернуться в траекторию
    stopMotors();
    exited = true;
    glcdClear();
    glcd(1, 1, "Done.");
  }
}

// --- Движение ---

void moveForward(int time) {
  motor(DRIVE_MOTOR, 100, 100);
  delay(time);
  stopMotors();
}

void moveBackward(int time) {
  motor(DRIVE_MOTOR, -100, -100);
  delay(time);
  stopMotors();
}

void turnLeft(int time) {
  motor(DRIVE_MOTOR, 0, 100);
  delay(time);
  stopMotors();
}

void turnRight(int time) {
  motor(DRIVE_MOTOR, 100, 0);
  delay(time);
  stopMotors();
}

void stopMotors() {
  motor(DRIVE_MOTOR, 0, 0);
}
```

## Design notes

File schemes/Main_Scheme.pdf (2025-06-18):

# HuskyLens AI Camera

# MG90S - Servo Motor

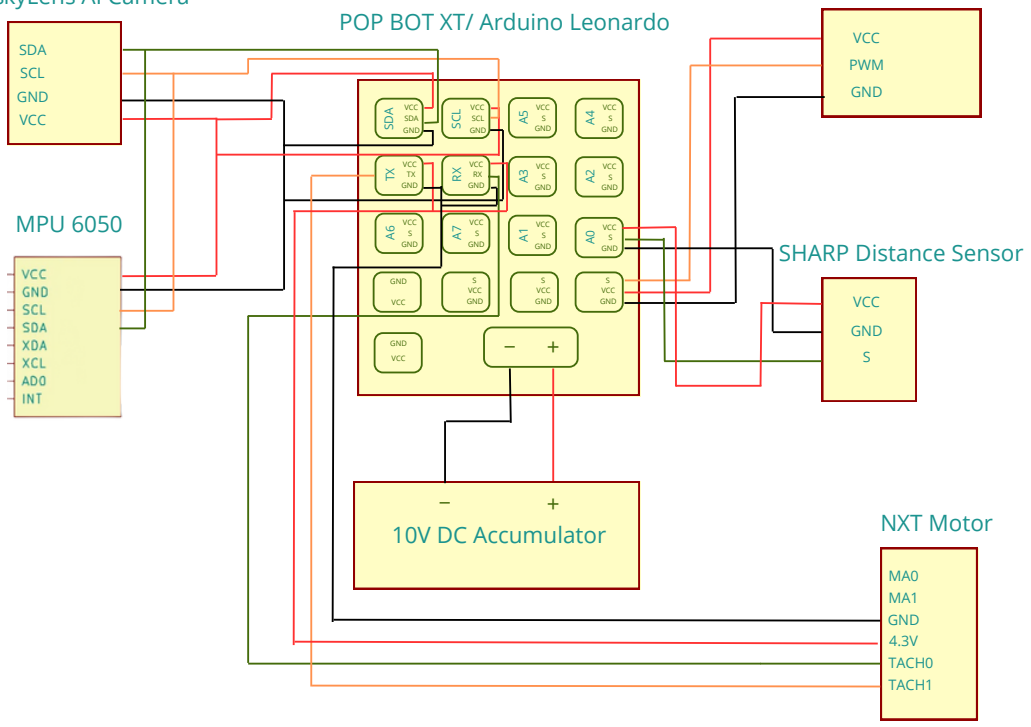
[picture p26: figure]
SCL; SDA; VCC SDA GND; VCC SCL SCL GND; VCC S GND A5; VCC S GND A4; VCC S GND A3; VCC S GND A2; VCC S GND A1; VCC S GND A0; VCC GND RX; VCC S GND A7; VCC GND TX; VCC S GND A6; VCC; GND; SVCC; POP BOT XT/ Arduino Leonardo; MPU 6050; PWM; GND S; SHARP Distance Sensor; 10V DC Accumulator; NXT Motor; MA0 MA1 GND 4.3V TACH0 TACH1

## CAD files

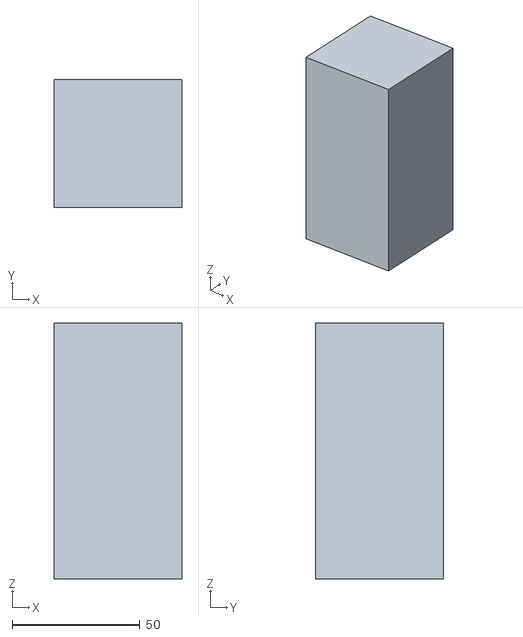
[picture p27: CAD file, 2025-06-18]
models/Pillar.stl
50.0 x 50.0 x 100.0
